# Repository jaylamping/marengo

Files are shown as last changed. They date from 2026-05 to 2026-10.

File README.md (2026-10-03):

<p align="center">
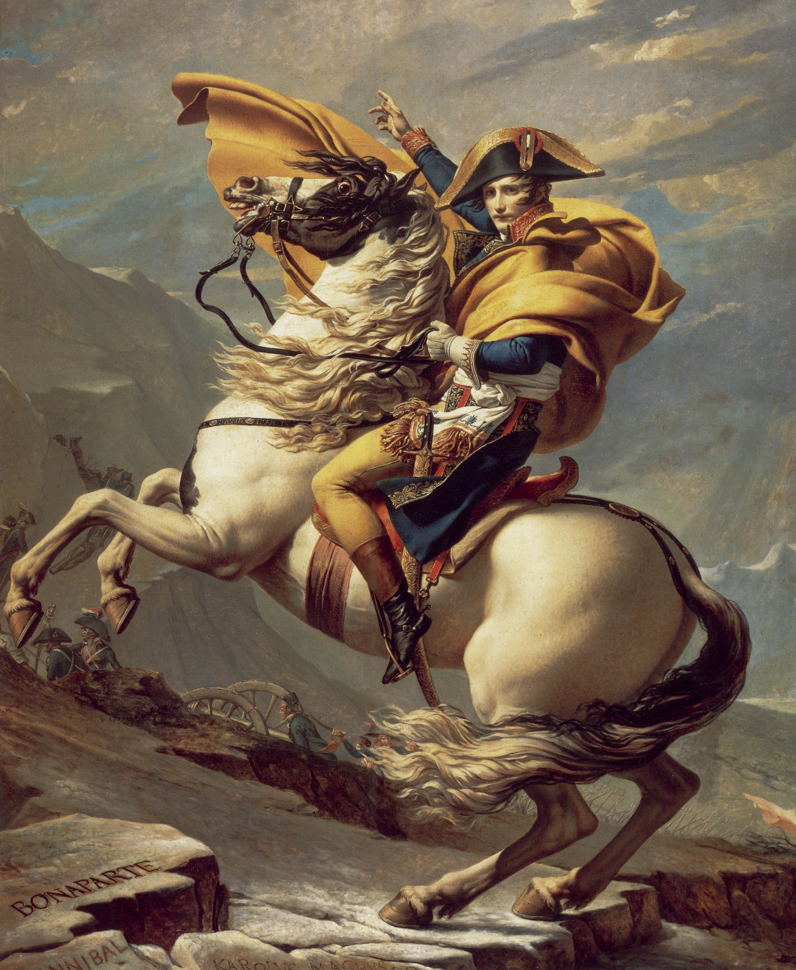
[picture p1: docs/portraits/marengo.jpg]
Jacques-Louis David, Napoleon crossing the Alps on Marengo
  
</p>

# Marengo

Returning to the project: read the [September 2026 repository review](docs/reviews/2026-09-29-repository-review.md) for the current architecture, bench checkpoint, outstanding defects, and ordered repair plan.

One repo for a personal humanoid: CAD, wiring, URDF, and the Rust runtime. SolidWorks and the harness docs define joints, frames, and limits. Control, safety, planning, and the operator UI read that same definition. When the robot changes in CAD, software should change with it.

## Naming

| Name | Role |
|---|---|
| Marengo | The robot (mechanical + electrical design, URDF, runtime) |
| Armée | Rust workspace: shared types, kinematics, crates |
| Chappe | Message bus between processes |
| Berthier | Realtime control |
| Davout | Safety supervision |
| Consul | Web frontend |
| Talleyrand, Fouché | Planner and Jetson vision/LLM: not built; the scaffolds were removed (2026-10-03 crate audit), [ADR 0014](docs/decisions/0014-jetson-perception-semantic-motion.md) holds the design |

Supporting crates: `armee-proto` (protobuf codegen), `armee-kinematics`, `robstride` (CAN driver). Wire schemas live in [`proto/`](proto/). More context: [docs/architecture.md](docs/architecture.md), [docs/roadmap.md](docs/roadmap.md) (full humanoid milestones; the arm is the current bench slice), [ADR 0001](docs/decisions/0001-protobuf-wire-types.md).

## Repository layout

```
marengo/
├── Cargo.toml              # Armée workspace root
├── proto/                  # Protobuf wire types
├── cad/                  # SolidWorks tree (local only); manifests tracked for MCP
│   └── manifests/        # MCP conventions + vendor registry (JSON)
├── hardware/             # Electrical, prints, BOM, hardware docs
│   ├── electrical/       # PDB, harness, CAN docs
│   ├── prints/             # STLs + slicer notes
│   ├── bom/                # Master BOM
│   └── docs/               # Kinematics, assembly, hardware ADRs
├── assets/                 # Exported from hardware, used by software
│   ├── urdf/marengo.urdf   # SW → URDF export
│   └── meshes/             # visual/ + collision/
├── crates/                 # Armée libraries (each has a README)
├── bins/                   # Pi runtimes and dev tools
├── consul/                 # Frontend (Vite + React + TS)
├── models/                 # ONNX policies (Git LFS)
├── config/                 # robot.yaml, motors.yaml, control.yaml, homing.yaml
├── docs/                   # Software architecture + ADRs
└── scripts/                # URDF export, deploy helpers
```

ONNX policies use Git LFS when present. See [.gitattributes](.gitattributes). CAD binaries are local-only — [cad/README.md](cad/README.md).

## Software

### Crates (`crates/`)

| Crate | Codename | README |
|---|---|---|
| `armee-proto` | Armée | [crates/armee-proto/README.md](crates/armee-proto/README.md) |
| `armee-kinematics` | Armée | [crates/armee-kinematics/README.md](crates/armee-kinematics/README.md) |
| `chappe` | Chappe | [crates/chappe/README.md](crates/chappe/README.md) |
| `berthier` | Berthier | [crates/berthier/README.md](crates/berthier/README.md) |
| `davout` | Davout | [crates/davout/README.md](crates/davout/README.md) |
| `robstride` | — | [crates/robstride/README.md](crates/robstride/README.md) |

### Binaries (`bins/`)

| Binary | Host | Purpose |
|---|---|---|
| `marengo-pi` | Raspberry Pi | Control, CAN, Chappe |
| `motor-repl` | Dev | Interactive motor exercise |

### Frontend

[consul/](consul/) is the operator UI and URDF viewer.

## Hardware workflow

1. Design in `cad/` (assemblies: `marengo.SLDASM`, sub-assemblies per limb).
2. Document limits and frames in [hardware/docs/kinematics.md](hardware/docs/kinematics.md).
3. Export URDF and meshes: `./scripts/export-urdf.sh` → `assets/`.
4. Wire and CAN: [hardware/electrical/wiring/](hardware/electrical/wiring/).

Vendor CAD (Robstride, Moteus, extrusions) lives under `cad/vendor/`.

## Build

Windows development and local CAD live at `J:\code\marengo`; macOS uses a host checkout of the same repository. Docker runs the full Linux workspace checks. Start with [Windows and macOS development](docs/windows-macos-development.md) and [onboarding](docs/onboarding.md).

```bash
docker compose build dev
just check
```

Native host setup is optional ([docs/dev-setup.md](docs/dev-setup.md)). Rust conventions for contributors and agents: [docs/rust-patterns.md](docs/rust-patterns.md), [AGENTS.md](AGENTS.md).

Deploy helper: `scripts/deploy-pi.sh`. systemd units: `scripts/systemd/`.

## CI

GitHub Actions runs `scripts/check.sh` in the dev image, plus optional `sim` and `vcan` jobs ([.github/workflows/ci.yml](.github/workflows/ci.yml)).

## License

MIT OR Apache-2.0. See [LICENSE-MIT](LICENSE-MIT) and [LICENSE-APACHE](LICENSE-APACHE).

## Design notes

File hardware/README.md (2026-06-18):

# Hardware

Physical robot design for Marengo: CAD, electrical, prints, and BOM. Mechanics and wiring are defined here first; software reads the exports.

## Layout

| Path | Purpose |
|---|---|
| [`../cad/`](../cad/) | SolidWorks parts, assemblies, vendor STEP, MCP manifests |
| [`electrical/`](electrical/) | PDB (KiCad), harness and CAN documentation |
| [`prints/`](prints/) | STL sources and slicer notes |
| [`bom/`](bom/) | Master BOM and sourcing |
| [`docs/`](docs/) | Kinematics, assembly, hardware ADRs |

## Active design

| Target | Status |
|---|---|
| Humanoid rev-a (G1/R1-class biped, 1524 mm, 23 DOF) | Torso frame 125×150×380 mm committed; pelvis/shell draft — [`docs/kinematics.md`](docs/kinematics.md) |
| Arm (4 DOF, bring-up) | First subsystem wired; [`config/robot.yaml`](../config/robot.yaml) + [`assets/urdf/arm_4dof.urdf`](../assets/urdf/arm_4dof.urdf), subset of humanoid arm kinematics |

Full-body runtime templates (not loaded until remaining joints are commissioned): [`config/robot_humanoid.yaml`](../config/robot_humanoid.yaml), [`config/motors_humanoid.yaml`](../config/motors_humanoid.yaml).

## Revision

When you cut a build, record the mechanical/electrical revision here (e.g. `rev-a`, date, known deltas from prior rev).

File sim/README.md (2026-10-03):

# Simulation fixtures and tests

`check-sim` smokes the minimal fixture plus the production model
[`assets/mjcf/marengo.xml`](../assets/mjcf/marengo.xml) (mirrors
[`assets/urdf/marengo.urdf`](../assets/urdf/marengo.urdf); body inertials are the
URDF CAD values — never hand-tuned). The Rust side (`sim-harness`) checks
URDF↔MJCF parity: joint names, axes, and range containment in the URDF hard
limits.

| File | Purpose |
|---|---|
| `fixtures/minimal.urdf` | Kinematics / URDF validation (`armee-kinematics`) |
| `fixtures/minimal.xml` | MuJoCo headless smoke (`check-sim`) |

## Run locally

```bash
just sim-check
```

Requires `docker/Dockerfile.sim` (MuJoCo Python).

## Environment

- `MARENGO_SIM_MODEL` — path to MJCF (default: `sim/fixtures/minimal.xml`)

[ADR 0003](../docs/decisions/0003-simulation-testing.md).

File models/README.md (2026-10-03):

# Models

ONNX policies and future Jetson-side model weights ([docs/roadmap.md](../docs/roadmap.md) M7; `fouche` was removed, design in [ADR 0014](../docs/decisions/0014-jetson-perception-semantic-motion.md)).

Large binaries use Git LFS (root [.gitattributes](../.gitattributes)).

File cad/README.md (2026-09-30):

# CAD (local only)

SolidWorks models and vendor imports are **not stored in git**. Keep your working tree under `cad/` on your machine (or a separate `marengo-cad` clone at the same path). Joint names, axes, and limits live in [hardware/docs/kinematics.md](../hardware/docs/kinematics.md). After export, runtime reads [assets/urdf/marengo.urdf](../assets/urdf/marengo.urdf).

Root assembly: `assemblies/marengo.SLDASM` (local).

## What stays in this repo

| Path | Purpose |
|---|---|
| `manifests/` | MCP conventions, vendor registry, design packages (text JSON) |
| `vendor/incoming/README.md` | Vendor intake notes |

## Local layout (gitignored)

| Path | Purpose |
|---|---|
| `assemblies/` | Root `marengo.SLDASM` and limb sub-assemblies |
| `parts/` | Marengo-authored `.SLDPRT` by subsystem |
| `vendor/` | Vendor STEP and imported `.SLDPRT` |
| `vendor/incoming/` | Drop downloads here before promoting to `vendor/` |
| `exports/` | Neutral STEP/STL from MCP `solidworks_export` |

## Setup

Software and local CAD sources live together at **`J:\code\marengo`** on Windows.
Open that host checkout for software and SolidWorks
([ADR 0018](../docs/decisions/0018-windows-macos-software-home.md)).

If CAD binaries are restored from backup/LFS archive, put them under that same
tree's `cad/`. macOS uses a host checkout of the same remote repository; ignored SolidWorks files require their own backup and transfer policy.

SolidWorks MCP allowed root is `${workspaceFolder}` (the host workspace) — your
local `cad/` tree must exist there for automation.

## Naming

- Authored part: `marengo_<subsystem>_<part>.SLDPRT` (example: `marengo_shoulder_pitch_mount_bracket_left.SLDPRT`)
- Authored assembly: `marengo_<subsystem>_asm.SLDASM` (example: `marengo_torso_asm.SLDASM`)
- Vendor import: `vendor_<mfg>_<mpn>_vendor.*` (STEP or `.SLDPRT` after import)

Regex targets: [manifests/cad-conventions.json](manifests/cad-conventions.json).

## Custom properties (authored parts)

Required on every Marengo-authored part and every vendor `.SLDPRT` in an assembly (MCP `marengo_design_review` checks the tree).

| Property | Authored example | Vendor import example |
|---|---|---|
| `process` | `cnc`, `print`, `layout` | `purchase` |
| `material` | `6061-T6`, `PETG` | `6063-T5`, `aluminum`, `RS03 actuator (vendor)` |
| `revision` | `A` | `vendor` |
| `owner` | handle or name | same as authored parts |

Batch-apply vendor properties (SolidWorks must be running):

```powershell
cd J:\code\solidworks-mcp
npm run build
npm run set:vendor-props
npm run promote:corner-bracket   # incoming → vendor_2028_corner_bracket_vendor + rewire torso asm
```

## Named reference geometry (URDF handoff)

Required on links and actuated joints before Brawner export:

| Name | Type | Purpose |
|---|---|---|
| `urdf_link_frame` | coordinate system | Link origin for URDF |
| `joint_axis` | axis | Revolute axis (right-hand rule) |
| `cable_exit` | plane or point | Harness routing |
| `mount_face` | plane | Actuator or bracket interface |

See [hardware/docs/kinematics.md](../hardware/docs/kinematics.md) for joint naming.

## Hardware folder

Place fasteners, inserts, and purchased hardware under a top-level feature folder named `Hardware` (see `manifests/cad-conventions.json`). Use real Toolbox or vendor STEP components, not cosmetic-only geometry, so BOM and `marengo_hardware_coverage` can count them.

## BOM alignment

1. Add a row to [hardware/bom/master-bom.csv](../hardware/bom/master-bom.csv) with `part_id` aligned to [manifests/vendor-assets.json](manifests/vendor-assets.json) `id` when possible.
2. Run `marengo_hardware_coverage` before major assembly saves.

## Workflow

1. Model in SolidWorks under `assemblies/marengo.SLDASM` (local).
2. Run `marengo_design_review` before saving assemblies.
3. Export URDF manually (Brawner) → `assets/urdf/marengo.urdf`.
4. Run `scripts/validate-urdf.sh` and update [hardware/docs/kinematics.md](../hardware/docs/kinematics.md) if joints changed.

Open [marengo.code-workspace](../marengo.code-workspace) from `J:\code\marengo` (marengo + solidworks-mcp). Build MCP after worker changes: `npm run build` in `J:\code\solidworks-mcp`. Allowed CAD root is `${workspaceFolder}`.

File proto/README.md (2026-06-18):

# proto

Wire-type definitions for all inter-service messages on [Chappe](../crates/chappe/).

- Edit `.proto` files under `marengo/v1/` (package `marengo.v1`). Never hand-edit generated Rust (`armee-proto`) or TypeScript (`consul/src/gen/`).
- Rust: [prost](https://github.com/tokio-rs/prost) via `crates/armee-proto/build.rs`
- TypeScript: [Buf](https://buf.build) + `@bufbuild/protobuf` from `consul/` (`npm run gen:proto`)
- On the wire: binary protobuf (`encode_to_vec` / `decode`), not JSON

## Prerequisites

- [`protoc`](https://grpc.io/docs/protoc-installation/) for `cargo build -p armee-proto`
- [`buf`](https://buf.build/docs/installation) for `consul` codegen (`npm run gen:proto`)

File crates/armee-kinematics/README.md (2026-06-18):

<p align="center">
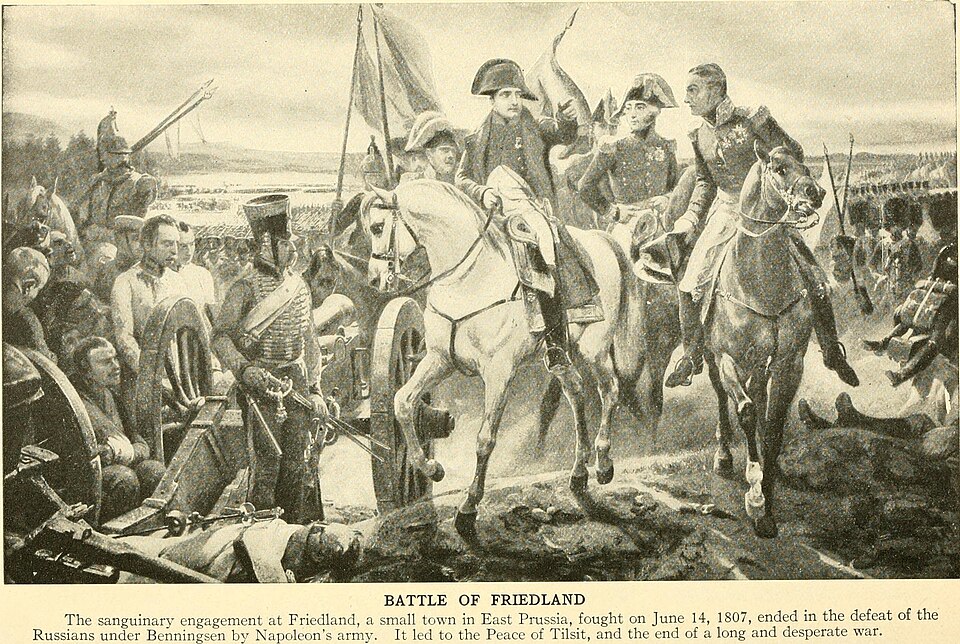
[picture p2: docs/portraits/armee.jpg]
Napoleon at Friedland
  
</p>

# armee-kinematics

Part of Armée, the Rust workspace for Marengo.

Loads joint limits and transforms from [`assets/urdf/marengo.urdf`](../../assets/urdf/marengo.urdf), aligned with [`hardware/docs/kinematics.md`](../../hardware/docs/kinematics.md). Used by planners, controllers, and sim collision checks.

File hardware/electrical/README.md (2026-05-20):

# Electrical

Power distribution, harnessing, and field bus topology for Marengo.

- [`pdb/`](pdb/) — Power Distribution Board (KiCad schematic, layout, BOM)
- [`wiring/`](wiring/) — Harness runs, CAN layout, connector pinouts

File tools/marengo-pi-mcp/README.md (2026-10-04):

# Marengo Pi MCP

MCP server for Marengo bench control on a Raspberry Pi over SSH. Runs on your dev machine; the Pi is only an SSH target.

## Setup

### SSH

```text
# ~/.ssh/config
Host marengo.local
  Hostname marengo.local
  User joey
  IdentityFile ~/.ssh/id_ed25519
```

Verify: `ssh joey@marengo.local 'echo ok'`

If mDNS fails, set `MARENGO_PI_HOST` in the environment before Cursor starts the MCP (or export it in your shell profile). Do not add it to `.cursor/mcp.json` — that env is hashed into Cursor’s MCP approval key and thrashing it auto-disables the server.

### Passwordless sudo (Pi)

`scripts/install-pi.sh` provisions these rules when run as root. For manual repair:

```sudoers
# Marengo MCP — passwordless sudo for bench scripts only (visudo -f /etc/sudoers.d/marengo-joey)
joey ALL=(root) NOPASSWD: /opt/marengo/scripts/can-up.sh *
joey ALL=(root) NOPASSWD: /opt/marengo/scripts/install-pi.sh
joey ALL=(root) NOPASSWD: /home/joey/marengo/scripts/install-pi.sh
```

Not full passwordless sudo. Only these paths.

Verify:

```bash
sudo -n /opt/marengo/scripts/can-up.sh can0 can1
sudo -n /home/joey/marengo/scripts/install-pi.sh   # staging → /opt (use this after deploy)
```

`sudo -n true` fails by design. After editing files under `~/marengo`, run `pi_install_staging` (MCP) or the staging install command above. Do not run `/opt/marengo/scripts/install-pi.sh` alone; it re-copies stale `/opt` content.

### Build MCP server

From repo root:

```bash
just mcp-build
```

Or:

```bash
cd tools/marengo-pi-mcp
npm install
npm run build
```

Restart the marengo-pi MCP server in Cursor after rebuilding.

If a tool still shows old behavior after `npm run build`, the Cursor MCP process is stale. Restart marengo-pi before retrying.

### Cursor `mcp.json`

Repo [`.cursor/mcp.json`](../../.cursor/mcp.json) uses `${workspaceFolder}` so the same file works on **Windows, macOS, and Linux/WSL**.

**WSL / Linux / macOS (software home):** mcp.json uses **`bash` + [`run-mcp.sh`](run-mcp.sh)**. Cursor's spawn PATH often lacks mise `node`, so bare `node` fails with `spawn node ENOENT`. The shell launcher finds mise (or `MARENGO_MCP_NODE`).

**Windows CAD session:** prefer [`run-mcp.cmd`](run-mcp.cmd) / [`run-mcp.ps1`](run-mcp.ps1) — Cursor often lacks Git `sh`/`bash`. Those wrappers exec [`dist/launch.js`](src/launch.ts) once `node` is resolved.

Profile / SSH defaults live in [`src/launch.ts`](src/launch.ts) / `run-mcp.sh` — **not** in `mcp.json` `env` (that thrash auto-disables the project MCP; see [ADR 0016](../../docs/decisions/0016-wsl-software-home.md)).

Open the marengo repo root as the Cursor workspace (WSL software session, or Windows UNC CAD session — ADR 0016).

`MARENGO_LOCAL_ROOT` is optional. The server derives the repo root from its install path. Override only for unusual clone layouts.

After clone or pull that touches MCP sources:

```bash
just mcp-build
```

Then restart the marengo-pi MCP server in Cursor.

**Stay enabled:** `.cursor/hooks.json` runs `session-start-marengo.js` on `sessionStart` (`--write --best-effort`) so disabled/unapproved state is scrubbed when a chat opens. If the server still shows as disabled after a config thrash:

```bash
# Quit Cursor first for a hard write, then:
just mcp-ensure-enabled --write
```

## Tool summary

| Class | Confirm | Examples |
|---|---|---|
| Read-only | No | `pi_logs_tail`, `pi_health`, `pi_homing_status`, `pi_motor_repl_status`, `pi_protocol_inspect`, `pi_gravity_preview`, `pi_imu_probe` |
| Admin | No | `pi_can_up`, `pi_sync_main`, `pi_sync_tree`, `pi_sync_bench_config`, `pi_sync_bench_urdf`, `pi_wait_deploy`, `pi_install_staging`, `pi_git_pull`, `pi_build` |
| Admin | Yes | `pi_restart_marengo_pi`, `pi_clean_tree` |
| Motion | Yes | `pi_motor_disable`, `pi_motor_recover`, `pi_set_zero`, `pi_hold_on`, `pi_hold_off`, `pi_bench_harness`, `pi_marengo_pi_script`, `pi_gravity_calibrate`, `pi_joint_calibrate`, `pi_motion_suite`, `pi_enable_soak` |

Weighted profile (`weighted_single_arm`, `arm_attached`) needs `confirm: true` and `confirm_weighted_motion: true`.

### One CAN owner

`motor-repl status` opens SocketCAN for its probe but bypasses Davout Supervisor
construction, so it sends no startup type-24 active-reporting burst.
`gravity-preview` reads the configured URDF model locally and does not open
CAN. `disable` and `set-zero` are CAN-owning commands; the latter uses Davout's
qualified reference workflow and an independent exit stop. `protocol-inspect`
(ADR 0037) also owns CAN: it stops every drive with Disable only, turns
reporting Off and reads firmware version, MCU id and registers (including the
0x7028 drive CAN timeout) one query at a time; it never enables or writes a
parameter, so `pi_protocol_inspect` needs no confirmation and prints a per-joint
firmware / CanTimeout table. MCP's ownership guard remains conservative: while
`marengo-pi` or any `motor-repl` process runs, `pi_motor_repl_status`,
`pi_protocol_inspect`, `pi_gravity_preview` and `pi_can_up` skip rather than
compete for the bus; stop `marengo-pi` with `pi_restart_marengo_pi` first.

Reference grants live only inside the `marengo-pi` process that acquired them
(ADR 0036). `pi_health`, `pi_homing_status` and `pi_sync_bench_config` (with
`install_to_opt`) therefore:

- while `marengo-pi` runs (`pgrep -x marengo-pi`), show per-joint homing from its own `RobotState`, read from the gateway's `/snapshot/robot/state`;
- otherwise print `no live marengo-pi session: reference grants are process-local (ADR 0036)` and the latest reference journal rows from `scripts/reference-journal-tail.py`, which opens `/opt/marengo/var/calibration/reference-journal.sqlite3` read-only. Journal rows are history and never grant a reference.

`install-pi.sh` runs no homing check; it prints one line pointing at the in-process procedure in [docs/homing.md](../../docs/homing.md).

Motion tools that open CAN take sole ownership of the bus for the session. These are `pi_motor_disable`, `pi_motor_recover`, `pi_set_zero`, `pi_hold_on`, `pi_hold_off`, `pi_marengo_pi_script`, `pi_gravity_calibrate`, `pi_joint_calibrate`, `pi_motion_suite`, `pi_enable_soak` and `pi_bench_harness`. Each session:

1. Stops `marengo-pi.service` with `sudo -n /usr/local/libexec/marengo/pi-restart-marengo-pi.sh stop`, the same helper `pi_restart_marengo_pi` uses. The service runs as `marengo` with `Restart=always`, so a bare `pkill` either fails or lets systemd start a second owner within 5 s.
2. Kills leftover `marengo-pi` processes owned by the deploy user.
3. Refuses to run (exit 1) if any `marengo-pi` or `motor-repl` is still running.
4. Waits for the bus to settle before every marengo-pi launch (`pi_hold_on`, `pi_marengo_pi_script`, `pi_motor_recover`, the harness session) and before restoring the unit. No `marengo-pi`/`motor-repl` may run, and the kernel CAN error counters (`rx_errors`, `rx_over_errors`, `tx_errors`, bus errors, error-passive, bus-off) must hold still for 0.5 s. The log shows `can settle: ok … <counters>`. marengo-pi latches a persistent Transport fault on any CAN error frame, and the mcp251x reports an RX FIFO overrun as one. A motor-repl run ending right before marengo-pi started (two `motor-repl disable`s, then marengo-pi's own type-24 burst) overran it at startup on 2026-10-03. If no window settles within 2 s, the session logs `can settle: FAIL` and refuses to start marengo-pi (exit 1); the unit restore warns and restarts anyway. Bench sessions run one pre-session `motor-repl disable` before the settle. `pi_hold_on` also logs `can errors after marengo-pi: …`, and runs its trailing `motor-repl disable` only once marengo-pi has exited. If marengo-pi still owns CAN, it prints `post-session bin/motor-repl disable skipped: …` and exits 1.
5. Restarts the unit when the session ends if it was active before, the same way `install-pi.sh` restores state. The unit comes back Disabled. The restart runs on every exit path, including errors and SIGHUP/SIGTERM. `pi_bench_harness` restarts it in a final `restore_marengo_pi_service` step.

To keep control off after a session, run `pi_restart_marengo_pi` with `mode: stop`.

### Reference and zero (no Motor Studio)

A current reference is granted only inside the process that acquires it. When that process exits, the grant ends. Acquiring a reference runs SetZero at the joint's current pose, so put each joint at its mechanical reference first.

- `pi_hold_on` and `pi_bench_harness` acquire references inside their own marengo-pi session. They send `home <joints> sign-tested` on stdin and wait until marengo-pi prints `reference <joint> current pos=…` for every joint. Then they send the plain `home`, `enable` and hold lines, so dwell sleeps begin only once the references are held. If a joint prints `reference <joint> failed|skipped: …` or `home failed: …`, or the wait passes 10 s per joint, the session sends `disable` and `quit` and exits 1.
  `pi_hold_on`, `pi_gravity_calibrate` and `pi_joint_calibrate` also await the plain `home` (until `homing verified`) and `enable` (until `enabled (operator=…)`). marengo-pi prints `enabled` only once enable has completed: every target's Enable is written (a just-zeroed drive's is held about 800 ms past its SetZero) and each target has fresh session feedback, after a `waiting for enable to complete` line. On `home failed:`, `enable failed|blocked|refused:` (including an Enable not complete within 2 s) or no answer within 10 s, the session sends `disable` and `quit` instead of any hold line and exits 1, and the tool result names marengo-pi's refusal line.
  `pi_marengo_pi_script` applies the reference wait to any `home <joints> sign-tested` line in its script.
- Both tools require `set_zero: true` **and** `at_mechanical_reference: true`. Without them they refuse before contacting the Pi, so a session never re-zeros at an arbitrary pose. `pi_hold_on` references only `joint` when you give one. If you omit it, it references every joint of the bench profile and holds `right_shoulder_pitch`. `pi_bench_harness` references `joints`, or every joint of the profile, once. It then runs all enable-requiring suites in **one** marengo-pi process: grants survive a clean `disable` but not the process, and re-zeroing per suite would accumulate the return-to-0 tracking error. Before each later suite it checks `$LOG` and stops if an earlier suite failed.
- `pi_set_zero` runs `motor-repl set-zero <joint> --sign-tested`, which prints its own qualified readback (`set-zero <joint> verified pos=…`), then `motor-repl disable`. The grant ends when motor-repl exits, so it doesn't let a later marengo-pi enable.
- `pi_motor_recover` never acquires a reference and never enables. After a fault the arm isn't attested at the reference, so it disables and reads `fault=` from `status` while Disabled.

```json
{
  "confirm": true,
  "joint": "right_shoulder_pitch",
  "set_zero": true,
  "at_mechanical_reference": true,
  "position_rad": 0.1
}
```

`config_dir` defaults to `/opt/marengo/config`. For a 3-DOF harness run, select the harness profile that exports `MARENGO_JOINT_SUBSET`. Don't point `MARENGO_CONFIG_DIR` at a separate bringup tree.

Profiles without a joint subset (`bare_motor`, `weighted_single_arm`, `arm_attached`) reference and gravity-gate exactly the master `config/robot.yaml` joints, `MASTER_JOINTS` in `src/bench-profiles.ts`: right shoulder pitch, shoulder roll, upper-arm yaw, elbow pitch and lower-arm yaw. Subset profiles use robot.yaml-order prefixes of that list. `test/bench-profiles.test.ts` fails when these drift from `config/robot.yaml` or `config/motors.yaml`.

### Gravity-model gate

`pi_hold_on` and `pi_bench_harness` run one shared gate (`src/gravity-gate.ts`) before anything can enable, for every bench profile. It applies the limb-playbook §4a/4b bar: a joint fails when its residual is **≥ 0.20 Nm**. On a failure the tool stops with `FAIL gravity_model_mismatch` and sends no reference, enable or hold line. `pi_hold_on` returns the report. The harness records `[FAIL] gravity_gate` and restores `marengo-pi.service`.

1. Before taking CAN, the gate reads the Pi clock and the gateway's `/snapshot/robot/state`. This read never touches CAN.
2. As sole CAN owner, it runs `motor-repl gravity-preview`. `pi_hold_on` runs it in its own `soleCanOwnerShell` session. The harness runs it as the `gravity_gate` step, after `can_up` and `motor_repl_status`. Non-zero poses use a full `robot.yaml`-order vector. Standalone `pi_gravity_preview` accepts no angles for the all-zero pose or exactly one angle per master joint in order; the harness's weighted previews also pass all five values.
3. It compares results per gated joint. Gated joints are the referenced joints, plus the hold joint for `pi_hold_on`.

| Basis | When | Residual |
|---|---|---|
| `measured` | Snapshot is at most 1 s old, and every gated joint is `drive_active` and `Verified` (marengo-pi is holding the arm) | `\|τ_meas − τ_g(q_published)\|`, where τ_meas is the gateway `effort` |
| `hanging_rest` | All other cases: no gateway, stale snapshot, or drives disabled | `\|τ_g\|` at the profile's `hangingRestRad` (every joint at its mechanical reference, arm down = 0, where physical gravity torque is ~0) |

In practice `hanging_rest` is the basis that applies. Both tools disable drives before their session, and a disabled Robstride carries no phase current: it reports ~0 Nm whatever the arm weighs, so a disabled reading is not a gravity measurement. `at_mechanical_reference: true` attests that the arm is at that rest pose. If none of the gated joints is in the gravity model, or the preview prints nothing (for example CAN is still owned), the gate fails closed with `FAIL gravity_gate_unavailable`.

Do not raise gains to get past this gate. Fix the URDF instead.

### `pi_gravity_calibrate`

Repeatable right-arm gravity-model calibration (`src/tools/gravity-calibrate.ts`; pre-flight, session runner and output directory shared with `pi_joint_calibrate` in `src/tools/calibration-session.ts`). It runs as **one** marengo-pi session, like `pi_hold_on`: `home <profile joints> sign-tested` (awaited), `home`, `enable`, then `hold-at` each static pose of `sweep_joint` with a `settle_sec + measure_sec` dwell, then `hold-at <sweep_joint> 0`, `status`, `disable`, `quit`. The position trace records τ_meas at every pose for the workstation fitter.

- **Sweep.** `sweep_joint` is `right_shoulder_pitch` (default poses `[0, 0.25, 0.48, 0.8, 1.2]` rad, at least 3) or `right_elbow_pitch` (default `[0, 0.25, 0.5, 0.75]`, with the pitch held at `fixed_pitch_rad`, moved there first and returned to 0 last). Poses (2–12, distinct) are sorted. An up pass overshoots to min − `approach_offset_rad` and visits every pose from below; a down pass overshoots to max + δ and visits every pose from above, so the fit can separate friction from gravity.
- **Opt-ins.** `confirm` (+ `confirm_weighted_motion` on weighted profiles), `set_zero` and `at_mechanical_reference` as for `pi_hold_on`, plus `skip_hanging_rest_gravity_check: true`. The gravity gate runs as usual but its hanging-rest `|τ_g|` mismatch ends in `SKIPPED gravity_model_mismatch (hanging rest) for gravity calibration` instead of refusing: the calibration exists to fix that model. Residuals are still reported; `gravity_gate_unavailable` and a measured-basis mismatch still refuse.
- **Limits.** Before any motion a read-only pre-flight (no CAN) reads the Pi `config_dir` `robot.yaml`, `control.yaml`, `motors.yaml` and the URDF `robot.urdf` names. Every target (overshoots included), the fixed pitch and the return pose 0 must lie in `[max(soft, hard) lower, min(soft, hard) upper]` (control.yaml `position_soft_*_rad` ∩ motors.yaml `bench.position_*_rad`), else it refuses naming joint, value and window. The session's sleep + reference budget must be ≤ 300 s.
- **Outputs.** `var/gravity-calibration/<TS>/` on the workstation (gitignored): `plan.json` (steps = the session's `hold-at` lines in order), `position-trace.csv` (Pi trace verbatim), `pi-marengo.urdf` and `config/{robot,control,motors}.yaml` (captured before motion), `bench-session.txt`. With `run_fit` (default) it runs `cargo run --release -q -p marengo-log-cli -- gravity-fit --dir <dir> --out-dir <repo>/docs/commissioning/calibrations --repo-urdf <repo>/assets/urdf/marengo.urdf [--fit mass:<link>|com:<link> …]` using absolute workspace paths; exit 2 means the fitter refused.
- **Never applied.** Review the proposed inertial patch, apply it to `assets/urdf/marengo.urdf`, then run `pi_sync_bench_urdf` as a separate explicit step (ADR 0017).

### `pi_joint_calibrate`

One session of the [right-arm calibration suite](../../docs/commissioning/right-arm-calibration-suite.md) (`src/tools/joint-calibrate.ts`): one joint sweeps while the others hold fixed poses. It runs as **one** marengo-pi session: `home <profile joints> sign-tested` (awaited), `home`, `enable`, a `hold-at` per non-zero `fixed_rad` pose (chain order), the sweep (`method`), then `hold-at <joint> 0` for every profile joint distal first (`return_home_sec` after each moved joint), `status`, `disable`, `quit`. `pi_gravity_calibrate` stays available unchanged.

- **Sweep.** `sweep_joint` is any of the five right-arm joints; `profile` defaults to `arm_attached`. Default poses are 5, evenly spaced across `amplitude_fraction` (0.25, 0.5 or 0.9) of the joint's soft ∩ hard window, centred on 0 (hanging rest, lowest gravity) and shifted to stay `0.05 rad` plus `approach_offset_rad` (static) or the 0.1 rad maximum wave amplitude (wave) inside the window. `poses_rad` (2–12) overrides them.
- **`method: "wave"` (default).** At each pose (ascending) a `hold-at` park at pose − a (`settle_sec`), then marengo-pi's in-loop `wave <joint> <pose−a> <pose+a> <cycles> <half_period>` at each speed; plan steps carry `pose_index`. A static hold rests anywhere inside the ±F_s stiction band; a wave drives through it both ways, and `gravity-fit` takes the up/down mean per q bin.
  - Amplitude `a = (F_s + 0.6 × max|τ_g at the poses|) / kp`, F_s = control.yaml friction `fs` (else `fc`), kp = `impedance.kp`, τ_g from the τ guard's batch; rounded up to 1 mrad, at least 0.025 rad; above 0.1 rad it refuses. `wave_amplitude_rad` overrides.
  - Speeds: 3, evenly spaced from 0.2 rad/s (gravity-fit's centre bin stays above its 0.15 rad/s deadband) to the admissible wave speed for ±a (0.8 × velocity cap, `position_trajectory_velocity_rad_s`, `position_trajectory_accel_rad_s2`); half period `π·a/v` to 0.01 s. `wave_speeds_rad_s` (2–3, each ≥ 0.2) overrides.
  - Cycles per speed: at least 2, enough for 1.5 × 10 samples per direction in gravity-fit's a/2-wide centre bin at `control.loop_hz`. `wave_cycles` overrides.
  - Adjacent poses must be more than 2a apart. `velocity_passes` refuses (static only); `approach_offset_rad` and `measure_sec` are unused.
- **`method: "static"`.** The `pi_gravity_calibrate` up and down hold passes, then the velocity passes: marengo-pi's in-loop `wave` once per `half_periods_s` entry, after a `hold-at` at `min_rad`. Default: a band up to 0.3 rad wide centred in the pose band, 2 cycles, at 25/50/75 % of the admissible peak speed (half periods rounded up to 0.05 s). `half_periods_s: []` runs holds only.
- **Opt-ins.** As `pi_gravity_calibrate`: `confirm`, `confirm_weighted_motion`, `set_zero`, `at_mechanical_reference`, `skip_hanging_rest_gravity_check: true`.
- **Pre-flight guard.** All before any motion, from the Pi's live `config_dir` and URDF:
  - Every hold target, overshoot, fixed pose and wave extreme lies in `[max(soft, hard) lower + 0.05, min(soft, hard) upper − 0.05]`; the return pose 0 lies in the window.
  - Peak wave speed `π·(max − min)/(2·half_period)` ≤ 0.8 × the joint's velocity cap (control.yaml joint > actuator group > motor type). It must also stay within the joint's `position_trajectory_velocity_rad_s` and `position_trajectory_accel_rad_s2`, and its descent above any `clamp_velocity` danger zone threshold (`peak·√(1 − u²)`, `u = (max(above, centre) − centre)/amplitude`) within the zone speed, all of which marengo-pi's wave admission enforces. Planned waves (motion suite, velocity passes, local waves at each pose) are sized to fit.
  - Total sleep + reference budget ≤ 300 s, else it refuses and suggests splitting the session.
  - τ guard: `|τ_g| × factor ≤ 0.8 ×` τ_ff cap on every profile joint, at configurations ≤ 0.05 rad apart along every commanded path. The paths are each fixed joint moving out in chain order (the distal-first return retraces them) and the sweep across all of its targets, poses and 0 (wave method: planned with the 0.1 rad maximum amplitude, a superset of the final waves). The cap is `min(URDF effort, motors.yaml torque_limit_nm, robot.yaml max_joint_torque_nm, motor-type tau_ff_max_nm)`. τ_g comes from one batched remote call, run as sole CAN owner like the gravity gate, that runs `motor-repl gravity-preview` once per distinct configuration with a full `robot.yaml`-order vector. A missing τ_g refuses. The wave method checks limits, speeds and the budget after this batch, once the amplitude is known.
  - τ guard factor (`src/tau-factor.ts`): 1.6 per joint, or `1 + max(3σ_A/A, 0.15)` for a joint listed in [`docs/commissioning/calibrations/applied-gravity.json`](../../docs/commissioning/calibrations/applied-gravity.json) when its accepted record is in the repo, the Pi URDF's gravity-model fingerprint (link masses and COMs, joint origins and axes; not limits) equals the entry's `urdf_gravity_sha256`, the Pi URDF carries the record's fitted COMs, and every other joint sits at the fit's fixed pose. A missing, unreadable or stale index or record keeps 1.6 (fails closed); the output lists each joint's factor and why. `npm run gravity-fingerprint [urdf]` (after `npm run build`) prints the fingerprint for a new entry. Details: [right-arm calibration suite](../../docs/commissioning/right-arm-calibration-suite.md#calibrated-joints-τ-guard-factor).
- **Outputs.** The `pi_gravity_calibrate` directory with `plan.json` version 2 plus `method`. Wave plans add `wave_amplitude_rad` and omit `approach_offset_rad`/`measure_sec`; static plans keep them. Steps carry `kind`: `hold` (`joint`, `target_rad`, `measure`, `pose_index`, `approach`), `fixed` (`joint`, `target_rad`) or `wave` (`joint`, `min_rad`, `max_rad`, `cycles`, `half_period_s`, and `pose_index` for wave-method local waves). `session_complete` is true only when marengo-pi exited 0 and the trace shows every step, in order. A hold or fixed step counts when `target_raw` changes to its target. A wave counts when it reaches its top `cycles` times and returns to its bottom. With `run_fit` the fit runs even on an incomplete session; the fitter uses completed steps only, and follows plan.json `method`.

### `pi_motion_suite`

Thorough single-joint motion test (`src/tools/motion-suite.ts`), scored per move by `scripts/analyze-position-trace.py --score-bench`. It reuses the `pi_joint_calibrate` session runner, so each session is one marengo-pi process: `home <profile joints> sign-tested`, `home`, `enable`, the motions, every profile joint back to 0 distal first, `status`, `disable`, `quit`. The sweep joint is traced every tick (`MARENGO_POSITION_TRACE_FULL_RATE_JOINTS`) so the τ_ff step is scorable.

- **Usable window.** The soft ∩ hard window (`max` of the lower limits, `min` of the upper) inset by 0.05 rad, narrowed to the run of 0.05 rad samples around 0 where model `|τ_g| × factor ≤ 0.8 ×` τ_ff cap on every profile joint (one batched `motor-repl gravity-preview`; factor as for `pi_joint_calibrate`). Refused under 0.2 rad. Gravity extremes are the largest-|τ_g| samples on each side of 0; a side within 0.15 rad of 0 has none. With the calibrated pitch (× 1.15; 1.15 × 2.66 Nm = 3.06 Nm ≤ 4 Nm) the master config's window is the full inset window [−1.038, 2.93] rad; unverified (× 1.6) it stops at 1.2 rad.
- **Speed-controlled moves.** `hold-at` always runs at the configured planner speed, so a move at a chosen speed is a single-cycle `wave a b 1 T` (a→b→a), with peak speed `speed_fraction × v_adm(b − a)`; `v_adm` = min(0.8 × velocity cap, trajectory velocity, √(accel · span/2)).
- **Sessions** (`sessions`, default all, in order):
  - `long_moves`: bands of `span_fractions` (25/50/90 %) of the window, centred on 0; one wave per `speed_fractions` (25/50/90 %).
  - `sweeps_and_reversals`: full-width waves at the same speeds; then per band `hold-at a`, `hold-at b`, and `hold-at a` again after the trapezoid time to half the move (a mid-move reversal).
  - `short_moves`: 0.02/0.05/0.1 rad out (toward 0) and back at each gravity extreme and at 0.
  - `gravity_extremes`: `hold_sec` (≥ 10 s) drift holds at both extremes, with the moves between them.
  - `repeatability`: 0 → end of the 25 % band → 0, `repeat_count` (5) times.
- **Budget.** Each session must fit 300 s with reference acquisition (50 s for five joints) and the return; a longer one splits at block boundaries into `<name>_1`, `<name>_2`, …. Master pitch config with the repo URDF (window [−1.038, 1.2] rad, upper bound τ): `long_moves` 156 s, `sweeps_and_reversals` 132 s, `short_moves` 134 s, `gravity_extremes` 87 s, `repeatability` 95 s.
- **Guards**, all before any motion of any session: every target and wave extreme ≥ 0.05 rad inside the window, wave speed and acceleration within the admission limits, the τ guard along every commanded path of every session, the budget, `confirm` (+ `confirm_weighted_motion`), `set_zero` + `at_mechanical_reference`. The gravity gate before each enable keeps its hanging-rest refusal.
- **Outputs.** Per session `var/motion-suite/<TS>/`: `plan.json` (version 1: session, window, extremes, steps, `budget_sec`, `session_complete`), `position-trace.csv`, `bench-session.txt`, `config/`, `pi-marengo.urdf`, `score.txt`. The result ends with a `session | ts | budget s | verdict` table and `overall: PASS|FAIL`. The suite stops at the first session that is refused, fails or is incomplete; a scorer FAIL does not stop it. `dry_run: true` returns the plan after every guard, without any session.

### `pi_enable_soak`

No-motion enable reliability check (`src/tools/enable-soak.ts`). Run it after firmware, wiring or software changes, before more supervised motion.

- **Cycles.** Each of `cycles` (1–50, default 20) is a **fresh** marengo-pi process, launched after its own CAN settle, so startup type-24 sync, streams inherited from the previous process, the post-SetZero blackout and the staggered Enable are exercised every time. Stdin is exactly `home <profile joints> sign-tested` (awaited), `home` (awaited), `enable <operator>` (awaited, polled every 20 ms and timed), `sleep dwell_sec` (0.5–10, default 2), `status`, `disable`, `quit`. It never sends hold, gravity, torque, impedance or wave lines; `test/enable-soak.test.ts` checks the script and the generated remote command for motion verbs.
- **Opt-ins.** `confirm`, `set_zero` and `at_mechanical_reference`. Every cycle re-zeroes at the current pose, so the arm must hang limp at its mechanical reference throughout. `profile` (default `arm_attached`) picks the referenced joints; subset profiles export their `MARENGO_JOINT_SUBSET`. `stop_on_fault` (default false) stops after the first unclean cycle. Plans estimated over 480 s (20 s + cycles × (6 s + dwell)) are refused.
- **Why neutral.** While operational=Active and control=Disabled, Berthier sends only kp=0, kd=0, velocity=0, torque_ff=0 MIT per active joint (a status solicit at the current pose), and Davout's filter and stop path keep it neutral. Only stdin hold/gravity/impedance/torque/wave lines or a Chappe testing command (`robot/testing/mit_command_batch`, forwarded by the gateway from Consul Testing hold/wave) leave ControlMode::Disabled. So each soak marengo-pi runs under `env -u MARENGO_CHAPPE_SOCKET`: stdin is its only command source, and the gateway shows no RobotState during the soak. Every MCP-started marengo-pi (soak or not) also claims motion ownership through `MARENGO_MOTION_OWNER=stdin` in the remote preamble (`src/env.ts`): a Consul tab can then only disable/stop it, and its refused enable/Testing/Set Zero commands are published as `motion_refused` events on `robot/audit/action` (see docs/safety.md, "Single motion owner").
- **Per cycle.** References acquired (n of joints), the enable outcome line, fault or refusal lines (Transport, DriveState, homing verify, watchdog, non-zero `fault=0x…`, ERROR lines, feeder/settle refusals), enable → `enabled` ms, can0 `rx_over_errors` and `rx_errors` before and after, and the exit status. A cycle is clean when it exited 0, printed `enabled (operator=…)`, acquired every reference and logged no fault line.
 - **Outputs.** One candump covers the whole session, as for the other bench tools. Each UP interface is recorded with an error mask (`can0,#FFFFFFFF`), so kernel CAN error frames (e.g. the mcp251x RX-overflow controller report) land in the same capture with kernel timestamps; `firmware-timing` decodes them into `kernel_error_frames` (timestamp, interface, error class, controller flags) and the soak report prints a short `kernel error frames:` section (diagnostic only, never PASS/FAIL). The bench log and candump are copied to `var/enable-soak/<TS>/` (gitignored) with `soak-summary.txt`, and `cargo run --release -q -p marengo-log-cli -- firmware-timing --json candump.log` writes `firmware-timing.json` when the checkout has the analyzer.
- **Verdict.** PASS only when every requested cycle ran clean, can0 `rx_over_errors` did not increase over the session, and firmware-timing ran and reported `non_neutral_mit.count` 0. A non-neutral frame is FAIL regardless of anything else, and so is a missing, failing or unparseable analyzer result (`wire-level neutral-MIT check unavailable`): the soak never passes without the wire-level proof.

```json
{ "confirm": true, "set_zero": true, "at_mechanical_reference": true, "cycles": 20, "dwell_sec": 2 }
```

### `pi_sync_main`

1. Local `git pull --ff-only` on `main` (fails if dirty)
2. `./scripts/deploy-pi.sh joey@marengo.local`
3. Remote `install-pi.sh` → `/opt/marengo`
4. Writes `/opt/marengo/.deploy-rev`

### `pi_restart_marengo_pi`

Stops leftover `marengo-pi` processes and restarts `marengo-pi.service` so Davout reloads boot config (URDF + YAML). Numerical Set Limits Apply hot-reloads live limits and write-behind URDF without restart ([ADR 0012](../../docs/decisions/0012-config-db-overrides.md) / [ADR 0017](../../docs/decisions/0017-bench-set-limits-urdf-expand.md)); use restart for binary deploy, structural wiring, or after a failed persist left disk stale. Requires `confirm: true`. Optional `mode: "stop"` skips systemd start. Does not touch `marengo-gateway`.

Canonical remote body: [`scripts/pi-restart-marengo-pi.sh`](../../scripts/pi-restart-marengo-pi.sh) (also used by `pi-remote.sh restart-marengo-pi` / `stop-marengo-pi`, and Consul `POST /control/restart-marengo-pi`). MCP embeds the local checkout copy so the tool works before the Pi has the new script installed.

```json
{ "confirm": true }
```

### `pi_sync_tree`

Sync the Pi staging checkout (`MARENGO_PI_STAGING_ROOT`, default `~/marengo`) with `origin/main` without building or installing. Fails if that tree is dirty. `pi_git_pull`, `pi_clean_tree` and `pi_build` work in the same checkout. `/opt/marengo` is the root-owned install tree and isn't a git checkout.

1. `git fetch origin`
2. `git checkout main`
3. `git pull --ff-only origin main`

## Session logs

Motion runs tee to `$MARENGO_ROOT/var/log/bench-latest.log`. Read with `pi_logs_tail` / `pi_logs_last_fault`.

Session registration calls `/opt/marengo/bin/marengo-log-cli` directly. If that binary is unavailable or registration/archive fails, MCP leaves the hot log, trace and candump files in place; it does not prune unarchived evidence.

### Motor recover (no Motor Studio)

```json
{ "confirm": true }
```

Tool: `pi_motor_recover`. Disable drives, brief `status` with `fault=0x…`, prints `RECOVER_OK` or `RECOVER_FAIL`. Optional: `"config_dir": "/opt/marengo/config"`; omission uses the same master directory.

## Skills

- [`.cursor/skills/marengo-pi-mcp/SKILL.md`](../../.cursor/skills/marengo-pi-mcp/SKILL.md) — log-first bench workflow
- [`.cursor/skills/marengo-pi-sync/SKILL.md`](../../.cursor/skills/marengo-pi-sync/SKILL.md) — sync-with-main deploy

Also [docs/pi-commissioning.md](../../docs/pi-commissioning.md).

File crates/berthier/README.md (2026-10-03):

<p align="center">
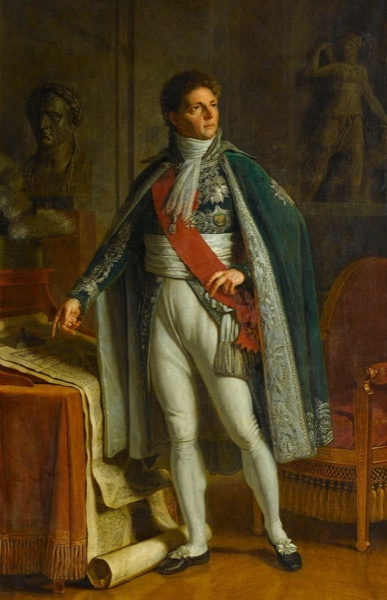
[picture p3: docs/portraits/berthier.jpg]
Louis-Alexandre Berthier
  
</p>

# berthier

Berthier runs the realtime control loop.

Trajectory tracking, mode switching, command output to motor drivers. Consumes joint setpoints (no planner crate exists; see [ADR 0014](../../docs/decisions/0014-jetson-perception-semantic-motion.md)) and limits from [Davout](../davout/).

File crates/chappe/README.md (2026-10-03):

<p align="center">
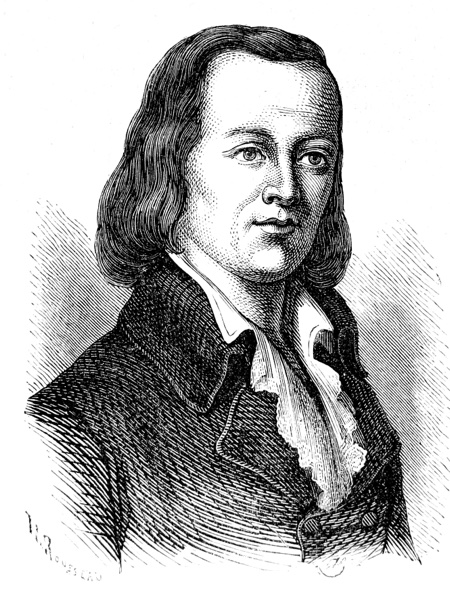
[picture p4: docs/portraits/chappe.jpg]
Claude Chappe
  
</p>

# chappe

Chappe is Marengo's message bus.

It connects runtime components (control, safety, diagnostics) between Pi and tools. Payloads are `Vec<u8>` binary protobuf from [`proto/`](../../proto/), encoded and decoded via [`armee-proto`](../armee-proto/) (`prost::Message::encode_to_vec` / `decode`). No JSON on the wire.

Operator gateway ([ADR 0008](../../docs/decisions/0008-chappe-webtransport-transport.md)): [`bins/marengo-gateway`](../../bins/marengo-gateway/) exposes HTTP CRUD and WebTransport to browsers (Consul). `marengo-pi` forwards publishes over a Unix socket (`MARENGO_CHAPPE_SOCKET`, default `/run/marengo/chappe.sock`).

Planned NATS/MQTT backends use the same bytes-on-the-wire contract.

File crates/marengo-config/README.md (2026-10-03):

# marengo-config

Loads [`config/robot.yaml`](../../config/robot.yaml). Call `resolve_urdf_path` before runtime when you need the production URDF.

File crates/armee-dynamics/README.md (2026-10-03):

# armee-dynamics

Gravity torques and dynamics helpers for Marengo control ([ADR 0005](../../docs/decisions/0005-dynamics-library.md)).

## API

- [`DynamicsModel::gravity_torques`](src/lib.rs) — feedforward for MIT `torque_ff`
- [`UrdfGravityModel`](src/lib.rs) — built from a URDF path + actuated joint list
- [`calibration`](src/calibration.rs) — fit link mass scale / COM offset to bench holding torques
  (`marengo-log-cli gravity-fit`; workflow in [limb playbook](../../docs/commissioning/limb-playbook.md#gravity-calibration-after-hardware-changes))

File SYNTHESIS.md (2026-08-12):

# Ascent-stall recovery — arena synthesis

## Base

**candidate-5** — explicit `AscentRecovery { Idle | Active { stalled_ms } }`; planner advances instead of freezing; existing lead clamp + stuck-lead resync provide bounded authority; fuse sticky across resync.

Parent initially preferred candidate-1 (freeze + lead-follow escalator). Cross-judge preferred candidate-5 for cleaner lifecycle and fewer load-bearing special cases (no resync-suppression footgun). Parent agreed: same authority class (reach `max_lead` P-torque), easier to extend.

## Grafts

| From | Kept | Why |
|---|---|-----|
| candidate-1 | `PlannerEvent::AscentBreakaway`, `ascent_stall_ms` on hold diag + 1 Hz log, motion-release test | Observability + mutation-resistant “progress clears fuse / planner resumes” lock without changing C5’s law |
| candidate-4 | fuse-survives-resync timing assertion (`fault_tick − fuse_armed ≤ 410`) | Locks sticky fuse against silent resync resets; no CSV schema change |

## Rejected

| Candidate / idea | Why |
|---|-----|
| candidate-1 as base | Lead-follow rewrite + resync suppression while frozen is load-bearing; removing the gate fail-opens |
| candidate-2 | Snap-resync at 0.03; test asserts `max_lead < 0.04` — never delivers breakaway torque |
| candidate-3 | Sticky fuse + onset, still freezes at ~0.03 — underpowered for the friction knee |
| candidate-4 as base / remove freeze alone | Same family as C5 but larger surface (CSV column); C5’s named state is the cleaner boundary |
| candidate-4 CSV `ascent_stall_ms` column | Contract churn; diag + 1 Hz log is enough |
| Unify freeze/resync at 0.03 without sticky fuse | Fail-open retry loop (C1 mutation) |
| Re-enable `approach_stuck_mit_pull` | Documented open-loop grind regression |

## Dropouts

None. All five candidates produced artifacts + `RATIONALE.md`.

## Verification

- `cargo test -p berthier`: 155 lib + 2 integration passed
- `cargo clippy -p berthier --all-targets -- -D warnings`: clean
- `cargo fmt --all -- --check`: clean

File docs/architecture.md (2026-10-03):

# Architecture

Current implementation status and known failures are recorded in the [September 2026 architecture and repository review](reviews/2026-09-29-repository-review.md). The working robot is the five-joint right bench arm; planning/perception and some physical homing/simulation capabilities shown below remain future work.

CAD, kinematics, and wiring describe the machine. The Rust workspace (Armée), message bus, control, safety, and planning consume that description. Scope and milestone order: [roadmap.md](roadmap.md).

Wire types are defined once in [`proto/`](../proto/) as Protocol Buffers and generated into Rust ([`armee-proto`](../crates/armee-proto/)) and TypeScript ([`consul/src/gen/`](../consul/)). [ADR 0001](decisions/0001-protobuf-wire-types.md).

## Data flow (high level)

```mermaid
flowchart LR
  HW[cad/ + hardware/docs] --> Assets[assets/]
  Assets --> KIN[armee-kinematics]
  Proto[proto/*.proto] --> AP[armee-proto]
  Proto --> ConsulGen[consul/src/gen]
  AP --> Chappe[Chappe bus]
  ConsulGen --> Consul[Consul UI]
  HW --> Consul
  Pi[marengo-pi] --> Chappe
  Gateway[marengo-gateway] --> Chappe
  Consul[Consul UI] -->|HTTP + WebTransport| Gateway
  Chappe -->|"binary protobuf"| Berthier[Berthier control]
  Berthier --> Davout[Davout safety]
  Davout --> Motors[robstride / moteus]
```

## Control stack boundaries

Motor path is fixed: Berthier → Davout → robstride. Each crate documents its boundary at the top of `src/lib.rs`.

| Crate | Owns | Must not |
|---|---|---|
| [`berthier`](../crates/berthier/) | Joint-space trajectory executor: `tau_g` + impedance → MIT batch | CAN, limits, Cartesian IK, behavior scripts |
| [`davout`](../crates/davout/) | Enable FSM, filter, watchdog, send | Trajectories, URDF dynamics |
| [`robstride`](../crates/robstride/) | MIT encode/decode, CAN I/O | Policy, safety |
| [`armee-dynamics`](../crates/armee-dynamics/) | `gravity_torques(q)` | CAN, commands |
| [`armee-kinematics`](../crates/armee-kinematics/) | URDF limits, joint lists | Control loop |
| [`marengo-config`](../crates/marengo-config/) | YAML types/loaders | Runtime enforcement |

## Crates and binaries

See the root [README](../README.md#software) for the naming map (Napoleonic corps → subsystem).

## Dev tooling

[`dev-setup.md`](dev-setup.md): `protoc`, `buf`, and regeneration workflow.

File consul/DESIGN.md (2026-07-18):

# Consul Design

**Consul** is the personal daily-driver operator cockpit for Marengo.

It exists for one person (you) who will live in it for hours every day while building, debugging, and tuning a 23-DOF humanoid. It must be the sexiest, smoothest, most *functional* robotics operator interface on the planet in 2026.

## The Only Filter

Every pixel, interaction, and feature must survive this question:

> Does this make me faster, more certain, or more in control of the physical machine right now?

If the answer is “no” or “only a little,” it does not exist.

## Current Phase

Consul is **wireframe + live telemetry** when `VITE_CHAPPE_*` is set. KPI cards, charts, inventory rows, and header badges still use placeholders by default; joint tracking, safety/mode badges, and inventory values can reflect real `RobotState` / `SafetyState` from `marengo-gateway` over WebTransport.

The **Simulation** tab is the planned home for Isaac Sim / Isaac Lab: viewport stream, play/pause/scenario controls, runtime metrics, and task logs. Same wireframe rules apply until the D2 Lab bridge shares `proto/` with the stack ([ADR 0003](../docs/decisions/0003-simulation-testing.md)).

## Core Principles

### 1. Information is sacred
- The goal is **understanding**, not data volume.
- Raw logs, metrics, and messages are only valuable when transformed into **actionable, time-synced, context-rich surfaces**.
- No infinite listviews. No firehoses. No “everything everywhere all at once.”
- The 3D view, plots, joint inspector, safety state, and event stream are all locked to the same time cursor. Scrubbing tells a story.

### 2. The 3D visualizer is first-class
- This is not a widget. It is the primary way the physical robot feels *present* on screen.
- Selection, highlighting, measurement, camera choreography, ghosting, contact viz, and exploded views must feel native and delightful.
- Tight bidirectional coupling: click a link in 3D → the rest of the app snaps to that joint/state. Scrub time → the model moves with every other surface.

### 3. Every tunable thing is a knob or dial
- If the robot exposes it in config, YAML, or at runtime (gains, limits, gravity compensation, safety zones, friction models, presets, behaviors…), it must be reachable and changeable from Consul with the same directness as turning a physical potentiometer.
- Changes must be instant to see in the 3D view and live plots.
- Perfect recall, versioning, and one-click restore of any previous “I liked it when it felt like this” state.

### 4. Smoothness and immediacy are non-negotiable
- The UI must feel *obscenely* good. 60 fps interactions, zero perceptible lag on knob drags or 3D camera moves, command palette that appears before you finish thinking the shortcut.
- React 19 compiler, modern web primitives, and obsessive attention to frame times and input latency.

### 5. Modern stack only
- We use the sharpest tools available in 2026 (React 19, WebTransport for messaging when the transport ADR lands, whatever state + data solution actually feels lightest and most powerful).
- We do not inherit 2018–2024 ROS/webviz patterns because “that’s what everyone does.”

## What “Functional + Sexy” Actually Looks Like Here

- You open Consul and in < 3 seconds you know the health and posture of the entire machine.
- You want to change a single joint’s `kd` while watching the 3D arm and the torque error plot — it feels like one continuous thought.
- When something goes wrong at 2 a.m., the thing that matters (the violated limit, the bad gain, the exact pose) is already highlighted or suggested.
- The interface disappears when you are in flow and only appears when you need leverage.

## Nice-to-Haves (for later)

- Teleoperation (high-quality, low-latency, with the same 3D + knob surface)
- Session recording + perfect replay with parameter snapshots
- Multi-robot / fleet views (only after the single-robot experience is god-tier)

## Anti-Patterns (will be rejected on sight)

- Marketing chrome, big logos, “delightful” animations that cost attention
- Enterprise SaaS visual language (Formant-style)
- Generic “dashboard” widgets that look good in screenshots but slow you down in practice
- Anything that makes the 3D view feel secondary
- Any feature whose primary justification is “other people might find this useful”
- GLINUI signature components (Meteor Shower, Typewriter, Pulsating Button) on operator data routes
- Frosted glass / backdrop blur on any surface (retired 2026-07 — the “Launch Day” reskin)
- Decorative motion or idle “alive” effects other than the dust backdrop drift
- Gradients for beauty (legibility aids like the vignette excepted)
- Playful empty states, illustrations, easter eggs

## Visual identity — “Launch Day”

Consul looks like the console a SpaceX engineer has open on launch day: calm, dense, perfectly aligned mono telemetry on near-black, where color is so scarce that a hue change means something. This is instrumentation for expensive hardware — nothing playful survives review.

- **Surfaces:** opaque layered panels (`--surface-0..3`) on a blue-black void, hairline borders (`--line` / `--line-strong`). No blur, no frost.
- **Accent:** amber phosphor (`--accent`, ≈ #FFB000) with armed/caution semantics — active controls, armed machine state, chart-commanded series, focus rings. Never decoration.
- **Status palette:** `--ok` green, `--warning` amber, `--fault` red, `--info` cyan (sparing). Nothing else carries chroma.
- **Type:** IBM Plex Sans for UI text; IBM Plex Mono for every number, log line, and micro-label (10px uppercase, 0.14em tracking). No display fonts.
- **Radius:** 4px. Sharp instruments, not consumer cards.
- **LEDs (`.led*`):** the only always-on glow; live-link pulses at 2.4s (reduced-motion aware).
- **Corner brackets (`.panel-brackets`):** semantic only — surfaces that act on hardware (e-stop, enable, armed tuning panels). Never on passive cards.
- **Dust backdrop:** soft gray particles drift slowly in a near-black void behind the fullscreen canvas. The air moves; the robot (telemetry) stays rock solid. This is the single sanctioned ambient motion — procedural, no stock imagery.

### Surface and motion tiers

| Tier | Surfaces | Skin | Motion |
|---|---|---|---|
| Chrome | sidebar, header, nav, tabs, control bar | opaque panel + hairline | mount ≤200ms; hover feedback |
| Data | tables, charts, log/inventory rows | panel shell; opaque rows | sort/filter ≤150ms; **no row animation** |
| Hero | empty states, sim idle, welcome | panel + void | stagger enter/exit allowed |

Glow is semantic only: armed (amber), fault (red), live-link (LED). Nominal state never glows. `prefers-reduced-motion` freezes the dust drift and LED pulse. Telemetry springs stay unchanged.

---

This document is the living filter. When in doubt, come back here. If a proposed component, layout, or library cannot be defended against these principles, it does not ship.

The bar is extremely high. That is the point.

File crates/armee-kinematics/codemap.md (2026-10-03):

# crates/armee-kinematics/

## Responsibility
URDF kinematic facts for the Marengo arm: joint limits, actuated joint indexing, and velocity-scaled position command envelope (ADR 0009). **No CAN, no control loop, no dynamics torques.** Serves as the geometric source of truth for config validation and runtime limit enforcement.

## Design

### Core types
- `JointLimits` — hard URDF position limits `(lower, upper)` from `<limit>` element; includes methods `contains(pos)` for checking within bounds.
- `JointLimitBounds` — hard limits plus optional `safety_controller` soft bounds from URDF (soft_lower, soft_upper). Methods: `hard_lower()`, `hard_upper()`, `soft_lower()`, `soft_upper()`.
- `JointLimitPolicy` — runtime limit policy built at startup by Davout from URDF + `motors.yaml` + `control.yaml`. Composed of: hard bounds, velocity cap, tau_ff max, LimitMarginConfig, danger zone rules. Used by Davout's filter pipeline and Berthier's position-hold setpoint clamping.
- `LimitMarginConfig` — per-joint margin tuning: `kinetic_margin_rad`, `stop_margin_rad`, `measured_fault_slack_rad`, `linear_margin_rate`.
- `UrdfError` — error enum for file loading, missing joints, parse failures.

### Modules
- `limits` — velocity-scaled position limit envelope (ADR 0009):
  - `limit_margin_rad(dq_cmd, margin)`: kinetic margin = linear_margin_rate * |dq_cmd| + stop_margin.
  - `effective_command_bounds(policy, q, dq_cmd)`: [lo, hi] = [hard_lower + margin, hard_upper - margin]; clamped to soft bounds when present.
  - `clamp_position_in_envelope(policy, q, dq_cmd, position_rad)`: clamp a commanded position into the effective envelope.
  - `clamp_hold_target(policy, q, dq_cmd, requested_rad)`: clamp operator hold-at target; soft bounds first, then envelope at dq_cmd.
  - `measured_position_fault(q, policy)`: true when measured position exceeds hard limits + fault slack.
  - `approach_velocity_cap(policy, q, dq_cmd, v_max)`: scale down cruise v_max when approaching an envelope wall.

### Key functions
- `load_urdf(path)` — parse a URDF file with urdf-rs.
- `joint_limits(robot, name)` — extract hard position limits for a named joint.
- `joint_limit_bounds(robot, name)` — hard limits plus safety_controller soft bounds (URDF soft is a fallback; Davout overwrites it from `control.yaml`). Errors (`UrdfError::InvalidLimits`) on non-finite/inverted hard or non-finite soft limits.
- `joint_entry_count(robot)` — total URDF joints (including fixed/mimic).
- `actuated_joint_names(robot)` — revolute/continuous/prismatic joints in URDF document order.
- `actuated_joint_count(robot)` — count of actuated joints.

### Fixtures module
- `fixtures::arm_4dof_urdf()`, `fixtures::marengo_urdf()`, `fixtures::invalid_urdf()` — checked-in test fixtures under `sim/fixtures/`.
- `fixtures::fixture_path(name)` — resolve fixture path.

## Flow
```
Startup (Supervisor::from_repo):
  → armee-kinematics::load_urdf(path)
  → armee-kinematics::joint_limit_bounds → JointLimitBounds
  → build_limits → JointLimitPolicy per joint
  → stored in Supervisor.limits

Per-tick (Davout filter and Berthier):
  → clamp_position_in_envelope(policy, q, dq_cmd, position_rad)
  → approach_velocity_cap(policy, q, dq_cmd, v_max)
  → clamp_hold_target(policy, q, dq_cmd, requested_rad)
  → measured_position_fault(q, policy) → fault in Davout check_feedback_position
```

## Integration
- **Depends on**: `urdf_rs` (URDF parser). No other workspace crate dependencies — deliberately leaf-level.
- **Depended upon by**: `armee-dynamics` (load_urdf for gravity model), `davout` (limit policy building + runtime clamping), `berthier` (position-hold setpoint clamping).
- **Does not**: compute tau_g, send commands, open files beyond URDF loading, run a periodic loop.
- **URDF is the geometric source of truth**: keep `hardware/docs/kinematics.md` in sync when joints change.

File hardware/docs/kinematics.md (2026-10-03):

# Kinematics

Single source of truth for joint names, axes, limits, link dimensions, and actuator assignment. Software, URDF, and bench config should match this doc.

| Model | URDF | Status |
|---|---|---|
| Right arm (5 DOF, live) | [`assets/urdf/marengo.urdf`](../../assets/urdf/marengo.urdf) | Current master SoT; same arm chain as the target humanoid, not a separate robot |
| Historical slices | [`assets/urdf/archive/seed-*/contributor.urdf`](../../assets/urdf/archive/) | Archive seeds only; never selected as the live runtime SoT |

Full-body target: [`config/robot_humanoid.yaml`](../../config/robot_humanoid.yaml) + [`config/motors_humanoid.yaml`](../../config/motors_humanoid.yaml). Live bench: master [`config/robot.yaml`](../../config/robot.yaml), [`config/motors.yaml`](../../config/motors.yaml), and [`assets/urdf/marengo.urdf`](../../assets/urdf/marengo.urdf) for the wired right 5-DOF arm. Old 3-DOF and 4-DOF contributors are preserved at [`archive/seed-arm_3dof_right/contributor.urdf`](../../assets/urdf/archive/seed-arm_3dof_right/contributor.urdf) and [`archive/seed-arm_4dof_right/contributor.urdf`](../../assets/urdf/archive/seed-arm_4dof_right/contributor.urdf). Milestones: [`docs/roadmap.md`](../../docs/roadmap.md).

---

## Humanoid mechanical reference

Design follows **Unitree G1** upper-body proportions and **Unitree R1** lower-body slimness, scaled to **1524 mm (5 ft)**. No wheels — biped only.

Design status: only the [upper torso 2020 frame](#torso-frame-committed) is committed for rev-a CAD. Pelvis, shell, battery bays, shoulder poke, and leg lengths below are draft and may change during layout. Joint names, axes, and actuator map stay authoritative.

| Parameter | Unitree G1 | Marengo (draft unless noted) |
|---|---|---|
| Standing height | 1320 mm | **1524 mm** |
| Body width | 450 mm | *draft* — shell TBD |
| Chest depth | 200 mm | *draft* — shell TBD |
| Thigh + shank (link length) | 600 mm | **660 mm** |
| Shoulder → hand reach | ~450 mm | **~480 mm** |
| Target mass (with battery) | ~35 kg | **38–42 kg** |
| Total DOF (v1, no hands) | 23 | **23** |

### Torso frame (committed)

Upper body structure is a single **2020 aluminum cage** (`marengo_upper_torso_frame` in CAD). Depth = **+X forward**, width = **±Y**, height = **+Z** from pelvis bottom origin.

| | Depth (X) | Width (Y) | Height (Z) |
|---|---|---|---|
| **Outer (2020 OD)** | **125** | **150** | **380** |
| **Inner clear (between rails)** | **85** | **110** | **~300** above waist bay |

| Feature | mm | Notes |
|---|-----|---|
| **Waist bay** (bottom of frame) | **≥ 40** | Reserved for `waist_yaw` RS03 + adapter; no shelves |
| **Chest zone** (above waist bay) | **~340** outer | Pi, PDB, harness; M18 bay *draft* |
| **Bottom interface** | — | Bottom rail → waist adapter → pelvis ring (*pelvis draft*) |
| **Top interface** | Z = **495** from pelvis bottom | Shoulder RS03 mounts on outer Y faces (*poke draft*) |

Vertical: **380 mm** = waist joint plane → shoulder plane when pelvis height remains **115 mm** (draft).

### Link dimensions (mm)

Floor → crown must sum to **1524 mm**. Values marked *draft* are CAD targets until vendor STEP and layout freeze.

| Segment | Length | Floor → landmark |
|---|---|---|
| Foot (sole → ankle axis) | 80 *draft* | ankle @ 80 |
| Shank (ankle → knee) | 325 *draft* | knee @ 405 |
| Thigh (knee → hip) | 335 *draft* | hip @ 740 |
| Pelvis block | 115 *draft* | waist @ 855 |
| Torso (waist → shoulder) | **380** | shoulder @ **1235** |
| Neck | 65 *draft* | |
| Head (chin → crown) | 224 *draft* | crown @ **1524** |

| Part | Size (mm) | Status | Notes |
|---|---|---|---|
| **Upper torso frame** | **125 × 150 × 380** outer; **85 × 110** inner clear | **committed** | 2020 cage; see [torso frame](#torso-frame-committed) |
| Pelvis ring | ~215 × 260 × 115 outer *draft* | draft | Wider than torso; main pack bay TBD |
| Main battery envelope | ~185 × 165 × 90 *draft* | draft | Pelvis; max Wh TBD |
| M18 HD12 aux bay | ~168 × 98 × 112 *draft* | draft | Upper back cantilever |
| Shoulder outer width | ~230 *draft* | draft | 150 frame + RS03 poke (~40 mm/side); verify STEP |
| Hip span (joint centers) | ~250 *draft* | draft | R1-class; splayed mounts |
| Foot (each) | 250 × 115 × 80 *draft* | draft | Toe-heavy for CoM |
| Head | 175 × 160 × 224 *draft* | draft | Skipped in v1 CAD |
| Upper arm (per side) | 215 *draft* | draft | |
| Forearm (per side) | 195 *draft* | draft | |
| Hand / gripper stub | 90 *draft* | draft | v1 — no dexterous hand |

### Leg kinematic tree (each side)

Pelvis → **hip yaw** → **hip roll** → **hip pitch** → thigh → **knee** → shank → **ankle pitch** → **ankle roll** → foot.

Yaw is the outboard joint at the pelvis (G1/H1-style). Document any CAD reversal in the assembly drawing; joint names and axes here are authoritative.

---

## Actuator assignment (humanoid)

Peak torque ratings from [ADR 0002](decisions/0002-robstride-protocol.md) (confirm in vendor PDF before production).

| Model | Peak τ | Count | Joints |
|---|---|---|---|
| **RS04** | 120 Nm | **4** | `left_hip_pitch`, `right_hip_pitch`, `left_knee`, `right_knee` |
| **RS03** | 60 Nm | **9** | `left/right_hip_roll`, `left/right_hip_yaw`, `waist_yaw`, `left/right_shoulder_roll`, `left/right_shoulder_pitch` |
| **RS02** | 17 Nm | **8** | `left/right_ankle_pitch`, `left/right_ankle_roll`, `left/right_upper_arm_yaw`, `left_elbow`, `right_elbow_pitch` |
| **RS00** | 17 Nm | **2** | `left_wrist`, `right_lower_arm_yaw` |

**Leg rationale:** RS04 on **inner hip pitch** (primary stance/swing load) and **knee** (single-support peaks, G1-class ~90 Nm knee). RS03 on **outer hip** roll/yaw. RS02 on ankles.

**Arm rationale:** RS03 shoulders (same as bring-up arm); RS02 for yaw, elbow; RS00 for wrists (5 DOF per arm, G1-aligned).

---

## Humanoid joint table

Mirror limits left/right unless noted. Effort column = motor peak τ (Nm). Angles in radians unless noted.

### Waist (1 DOF)

| Joint | Actuator | Parent → Child | Axis | Lower | Upper | Effort | Notes |
|---|---|---|---|---|---|---|---|
| `waist_yaw` | RS03 | pelvis → torso | Z | -2.71 | 2.71 | 60 | G1: ±155° |

### Left leg (6 DOF)

| Joint | Actuator | Parent → Child | Axis | Lower | Upper | Effort | Notes |
|---|---|---|---|---|---|---|---|
| `left_hip_yaw` | RS03 | pelvis → left_hip_yaw_link | Z | -2.76 | 2.76 | 60 | G1: Y ±158° |
| `left_hip_roll` | RS03 | yaw → left_hip_roll_link | X | -0.52 | 2.97 | 60 | G1: R −30°..+170° |
| `left_hip_pitch` | RS04 | roll → left_thigh | Y | -2.69 | 2.69 | 120 | **Inner hip**; G1: P ±154° |
| `left_knee` | RS04 | thigh → shank | Y | 0.0 | 2.88 | 120 | G1: 0–165°; no hyperextension |
| `left_ankle_pitch` | RS02 | shank → left_foot | Y | -1.0 | 0.8 | 17 | Tune after foot CAD |
| `left_ankle_roll` | RS02 | pitch → left_foot | X | -0.5 | 0.5 | 17 | `kd` max **5** |

### Right leg (6 DOF)

Same limits as left; roll/pitch signs follow right-hand URDF convention.

| Joint | Actuator | Parent → Child | Axis | Lower | Upper | Effort |
|---|---|---|---|---|---|---|
| `right_hip_yaw` | RS03 | pelvis → right_hip_yaw_link | Z | -2.76 | 2.76 | 60 |
| `right_hip_roll` | RS03 | yaw → right_hip_roll_link | X | -2.97 | 0.52 | 60 |
| `right_hip_pitch` | RS04 | roll → right_thigh | Y | -2.69 | 2.69 | 120 |
| `right_knee` | RS04 | thigh → shank | Y | 0.0 | 2.88 | 120 |
| `right_ankle_pitch` | RS02 | shank → right_foot | Y | -1.0 | 0.8 | 17 |
| `right_ankle_roll` | RS02 | pitch → right_foot | X | -0.5 | 0.5 | 17 |

### Left arm (5 DOF)

| Joint | Actuator | Parent → Child | Axis | Lower | Upper | Effort | Notes |
|---|---|---|---|---|---|---|---|
| `left_shoulder_pitch` | RS03 | torso → left_shoulder_pitch_link | Y | -0.9 | 3.17 | 60 | Soft −50°…+180° (`safety_controller`); **upright hazard** when q > ~0.5 rad |
| `left_shoulder_roll` | RS03 | pitch → left_shoulder_roll_link | X | -1.57 | 1.57 | 60 | Torso-mounted pitch; roll on arm sub-asm |
| `left_upper_arm_yaw` | RS02 | pitch → left_upper_arm | Z | -1.57 | 1.57 | 17 | |
| `left_elbow` | RS02 | upper_arm → left_forearm | Y | 0.0 | 2.5 | 17 | **Upright hazard** — verify G-comp sign |
| `left_wrist` | RS00 | forearm → left_hand | Y | -1.6 | 1.6 | 17 | G1 wrist pitch band ~±92.5° |

### Right arm (5 DOF)

| Joint | Actuator | Parent → Child | Axis | Lower | Upper | Effort |
|---|---|---|---|---|---|---|
| `right_shoulder_pitch` | RS03 | torso → right_shoulder_pitch_link | Y | -0.9 | 3.25 | 60 |
| `right_shoulder_roll` | RS03 | pitch → right_shoulder_roll_link | X | -0.05 | 3.14159 | 60 |
| `right_upper_arm_yaw` | RS02 | pitch → right_upper_arm | Z | -1.57 | 1.57 | 17 |
| `right_elbow_pitch` | RS02 | upper_arm → right_forearm | Y | -0.50 | 1.2 | 17 | **Upright hazard** — verify G-comp sign |
| `right_lower_arm_yaw` | RS00 | forearm → right_hand | Y | -1.6 | 1.6 | 17 |

These are the design limits. The bench URDF carries the wider taught hard envelope ([ADR 0017](../../docs/decisions/0017-bench-set-limits-urdf-expand.md), listed below); Davout intersects it with the measured bounds in `config/motors.yaml`. URDF soft limits are pitch `[-0.872665, 3.20]`, roll `[-0.05, 3.14159]`, yaw `[-1.57, 1.57]`, and elbow `[-0.50, 1.15]` rad per [ADR 0009](../../docs/decisions/0009-dynamic-position-limit-envelope.md).

Right-arm joint origins and link inertials come from CAD as of 2026-10-03 ([derivation](../../docs/commissioning/right-arm-urdf-from-cad-2026-10-03.md)). Printed-part masses are infill estimates until weighed. Re-run the MuJoCo cross-check after changes ([ADR 0005](../../docs/decisions/0005-dynamics-library.md)).

---

## Live 5-DOF right bench arm

This promoted subset of humanoid arm kinematics is the live master model in
[`assets/urdf/marengo.urdf`](../../assets/urdf/marengo.urdf) and is wired per
[`config/robot.yaml`](../../config/robot.yaml).

| Joint | Actuator | Parent → Child | Axis (joint) | Lower (rad) | Upper (rad) | Effort (Nm) | Notes |
|---|---|---|---|---|---|---|---|
| `right_shoulder_pitch` | RS03 | base_link → right_shoulder_pitch_link | Y | -1.43134 | 3.25 | 60 | Soft `[-0.872665, 3.20]`; **upright hazard** when q > ~0.5 rad |
| `right_shoulder_roll` | RS03 | pitch → right_shoulder_roll_link | X | -0.099415 | 3.22308 | 60 | Soft `[-0.05, 3.14159]` |
| `right_upper_arm_yaw` | RS02 | roll → right_upper_arm_link | Z | -1.57 | 1.57 | 17 | Soft equals hard |
| `right_elbow_pitch` | RS02 | upper_arm → right_forearm_link | Y | -1.63191 | 1.60728 | 17 | Soft `[-0.50, 1.15]`; **upright hazard** — verify G-comp sign |
| `right_lower_arm_yaw` | RS00 | forearm → right_hand_link | Y | -3.24409 | 3.24409 | 17 | Soft `[-1.55, 1.55]`; CAN id **5** on `can0`; in CAD the RS00 axis runs along the forearm (Z at q = 0) |

Hard limits are the taught envelope from the Pi URDF on 2026-10-03 ([ADR 0017](../../docs/decisions/0017-bench-set-limits-urdf-expand.md)). Geometry from CAD: the roll axis crosses the pitch axis 73.5 mm outboard of the pitch output face; the elbow axis is 230.4 mm below that point; the RS00 output face is 99.7 mm below the elbow axis. The bench base frame has the arm's front at −X and outboard at +Y ([derivation](../../docs/commissioning/right-arm-urdf-from-cad-2026-10-03.md)).

---

## Upright / elevated poses

Documented incident (arm bring-up): arm elevated, control stopped, arm fell without gravity feedforward. Applies to **`right_shoulder_pitch`** and **`right_elbow_pitch`** on the live bench arm and to the corresponding full-humanoid joints.

Before bring-up tests with elevated shoulder/elbow:

1. Run per-joint `torque_ff` sign test.
2. Use **GravityComp** only until impedance is tuned.
3. Apply `danger_zones` in `config/control.yaml` for `right_shoulder_pitch` + downward velocity.

Leg bring-up: start with **hip pitch** and **knee** RS04 sign tests under load before closing the ankle loop.

---

## Frames

| Frame | Use |
|---|-----|
| `base_link` / pelvis | Biped origin; pelvis `urdf_link_frame` on CAD pelvis (*pelvis draft*) |
| `torso_link` | Upper torso 2020 frame; shoulder **pitch** RS03 inside cage at shoulder plane (rev-a layout) |
| `left_foot` / `right_foot` | Sole contact; Z = floor in standing neutral |
| `left_hand` / `right_hand` | Tool frame placeholder (TCP when gripper defined) |
| `right_forearm_link` | Live right-arm bench tool frame (full humanoid: `left_hand` / `right_hand`) |

Named CAD geometry: see [cad/README.md](../../cad/README.md).

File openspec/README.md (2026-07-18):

# SDD / OpenSpec

Spec-driven development artifacts for Marengo. Default store mode is **openspec** (files only; no memory MCP).

## Layout

```
openspec/
├── config.yaml          # Project context, testing, phase rules
├── specs/               # Main specs (source of truth after archive)
└── changes/
    ├── archive/         # Completed changes (YYYY-MM-DD-{slug}/)
    └── {slug}/          # Active change artifacts + state.yaml
```

## Active change

- **log-api-error-states** — SDD onboarding cycle (Consul log-api error/loading states)

Run `/sdd-explore log-api-error-states` to start the explore phase.

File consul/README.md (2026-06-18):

<p align="center">
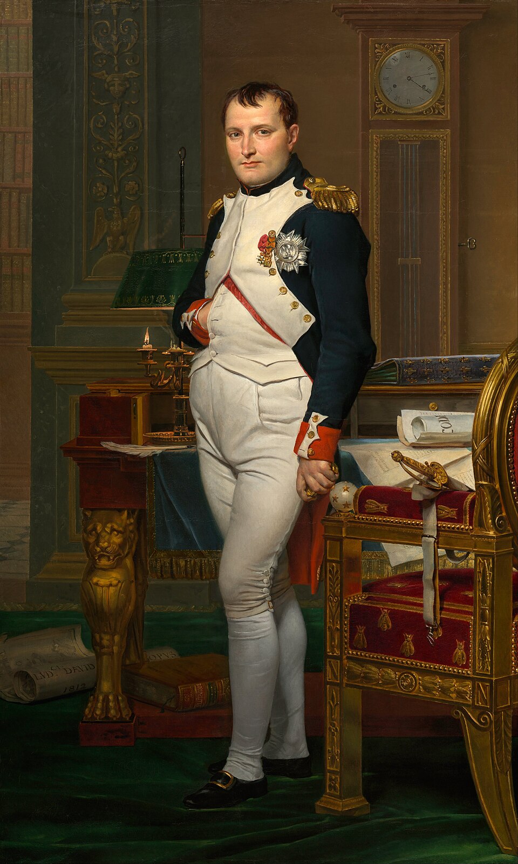
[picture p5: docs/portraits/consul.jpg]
Napoleon in his study
  
</p>

# consul

Consul is the operator frontend for Marengo (Vite + React + TypeScript): robot state, URDF visualization, tuning. Loads `assets/meshes/visual/` and talks to the runtime over Chappe (binary protobuf, same schemas as [`proto/`](../proto/)).

Vite + React 19 dashboard with optional live Chappe telemetry ([ADR 0008](../docs/decisions/0008-chappe-webtransport-transport.md)).

- Robot-hosted (default on Pi): open `https://marengo.local:8444` after `install-pi.sh` / `deploy-pi.sh --install`. Endpoints come from the page origin; WebTransport uses `:8443/chappe`.
- Local dev: copy `.env.example` → `.env.local` with `VITE_CHAPPE_*`, then `npm run dev` on `:5173`.

URDF visualization is still upcoming.

## Development

Requires [`buf`](../docs/dev-setup.md) and Node.js.

```bash
npm install
npm run gen:proto   # ../proto → src/gen/ (gitignored)
npm run build       # tsc --noEmit (CI parity)
```

`gen:proto` runs automatically before `dev` and `build`.

Generated TypeScript uses `@bufbuild/protobuf`. Never edit `src/gen/` by hand.

`DESIGN.md` and `TECH.md` cover principles and current tech choices.

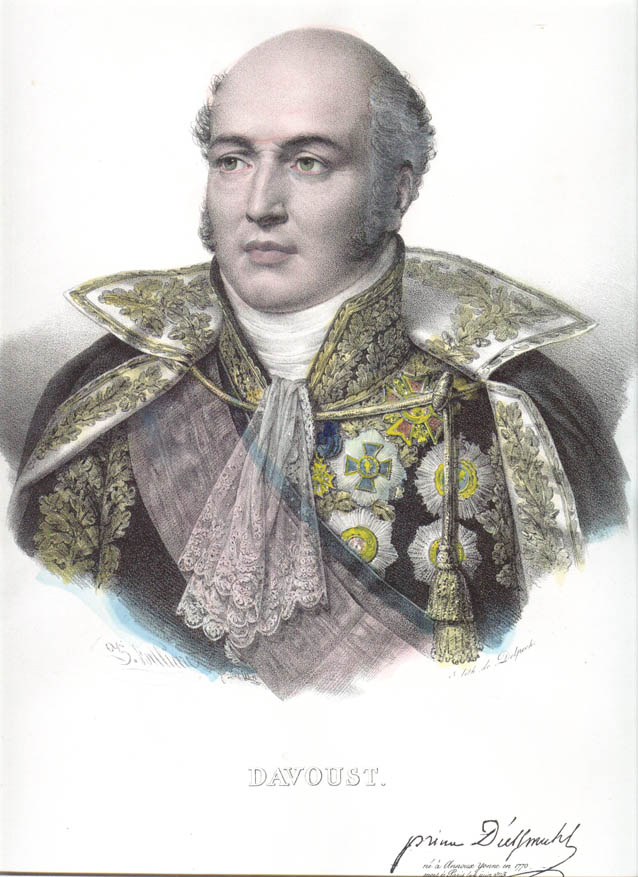
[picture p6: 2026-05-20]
docs/portraits/davout.jpg

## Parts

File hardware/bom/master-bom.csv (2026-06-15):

part_id | description | qty | vendor | mpn | notes
actuator_rs04 | Robstride RS04 joint motor | 4 | Robstride | RS04 | left/right hip_pitch + left/right knee; 120 Nm peak
actuator_rs03 | Robstride RS03 joint motor | 9 | Robstride | RS03 | hip roll/yaw x4 + waist_yaw + shoulder roll/pitch x4; 60 Nm peak
actuator_rs00 | Robstride RS00 joint motor | 2 | Robstride | RS00 | left/right wrist; 17 Nm peak
actuator_rs02 | Robstride RS02 joint motor | 8 | Robstride | RS02 | ankle x4 + arm yaw/elbow x4; 17 Nm peak
stock_vendor_2020_black_extrusion | IXGNIJ 2020 T-slot EU black 500mm (4-pack) | 2 | Amazon | B08Y8KCJW4 | Purchase only (not instanced). Registry: vendor_2020_black_extrusion.
frame_2020_vertical_340 | Torso vertical corner post 340mm | 4 | cut |  |  | Instances frame_2020_vertical_{back|front}_{left|right}_340
frame_2020_bottom_left_100 | Torso bottom left rail 100mm | 1 | cut |  |  | Config L100; depth rail (140 outer / 100 inner)
frame_2020_bottom_right_100 | Torso bottom right rail 100mm | 1 | cut |  |  | Config L100
frame_2020_top_left_100 | Torso top left rail 100mm | 1 | cut |  |  | Config L100
frame_2020_top_right_100 | Torso top right rail 100mm | 1 | cut |  |  | Config L100
frame_2020_bottom_front_110 | Torso bottom front rail 110mm | 1 | cut |  |  | Config L110
frame_2020_bottom_rear_110 | Torso bottom rear rail 110mm | 1 | cut |  |  | Config L110
frame_2020_top_front_110 | Torso top front rail 110mm | 1 | cut |  |  | Config L110
frame_2020_top_rear_110 | Torso top rear rail 110mm | 1 | cut |  |  | Config L110
bracket_2028_corner | 2028 corner bracket 2020 T-slot | 16 | cut |  |  | GrabCAD storm model; 8 cage corners × 2; purchase mankk B0FDKPLF8N
stock_bracket_2028_corner_kit | mankk 2028 corner bracket kit (30 pc) | 1 | Amazon | B0FDKPLF8N | Purchase only (not instanced)
print_shoulder_pitch_mount_bracket_left | PETG shoulder pitch mount bracket (left) | 1 | printed |  |  | marengo_shoulder_pitch_mount_bracket_left
print_shoulder_pitch_mount_bracket_right | PETG shoulder pitch mount bracket (right) | 1 | printed |  |  | marengo_shoulder_pitch_mount_bracket_right
print_waist_yaw_adapter | PETG waist yaw adapter plate | 1 | printed |  |  | marengo_waist_yaw_adapter
sensor_bno085 | Teyleten Robot GY-BNO085 9-DOF IMU | 1 | Teyleten | GY-BNO085 | torso IMU; I2C 0x4b (ADR high); Pi header i2c-1

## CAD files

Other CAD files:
cad/parts/marengo_shoulder_roll_bracket_right.SLDPRT
hardware/cad/exports/marengo_shoulder_roll_mount_bracket_left_revA.STL
hardware/cad/exports/marengo_shoulder_roll_mount_bracket_right_revA.STL

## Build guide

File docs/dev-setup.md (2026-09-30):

# Development setup

## Docker (recommended)

Open the host checkout (`J:\code\marengo` on Windows) and use Docker for full workspace checks. [Windows and macOS development](windows-macos-development.md) describes native frontend work, CAD, and Pi deployment. Dev container setup: [onboarding.md](onboarding.md). Pi bring-up: [pi-commissioning.md](pi-commissioning.md).

```bash
docker compose build dev
just check          # or: docker compose run --rm check
```

Optional:

- Dev Container: Reopen in Container (Cursor / VS Code), [`.devcontainer/`](../.devcontainer/)
- SocketCAN test harness: `just vcan` (Linux, privileged; creates `vcan0`/`vcan1` as test stand-ins for production `can0`/`can1`)
- sim: `just sim-check`

Production runtime uses SocketCAN interfaces named `can0`, `can1`, `can2`, etc. Bring them up on the robot before starting `marengo-pi`, for example:

```bash
sudo ip link set can0 type can bitrate 1000000
sudo ip link set can0 up
```

## Native / host (best-effort)

If you cannot use Docker, install tools matching [mise.toml](../mise.toml):

| Tool | Version |
|---|---|
| Rust | 1.88 (see [rust-toolchain.toml](../rust-toolchain.toml)) |
| Node | 24.16.0 (see [.nvmrc](../.nvmrc), [mise.toml](../mise.toml); matches CI/dev container) |
| protoc | 28.3 |
| buf | 1.47.2 |

### Node on Mac / Windows (avoid lockfile drift)

CI and the dev container use Node 24 (currently 24.16.x). Use mise (or nvm/fnm) so Mac and Windows match CI. Do not rely on an unpinned system Node.

[mise](https://mise.jdx.dev/) (Mac + Windows + Linux):

```bash
# once per machine
mise trust
mise install          # reads mise.toml → Node 24.16.0, Rust, buf, protoc

# in repo root — verify
mise exec -- node -v    # v24.16.0
cd consul && mise exec -- npm ci
```

Alternatives: nvm / fnm read [.nvmrc](../.nvmrc) or [.node-version](../.node-version).

Consul `package-lock.json` rules:

| Task | Command |
|---|---|
| Install deps (day-to-day) | `cd consul && mise exec -- npm ci` or `just consul-ci` |
| After editing `consul/package.json` | `just consul-lock` then commit lockfile |
| Never | `npm install` on Windows/Mac alone to refresh the lockfile — optional deps differ from Linux CI |

`consul/.npmrc` sets `engine-strict=true`; npm refuses Node outside `^24.16.0`.

```bash
# macOS examples (prefer `mise install` for pinned Node 24.16.0 — see above)
brew install rust protobuf bufbuild/buf/buf
git lfs install && git lfs pull

# Pi cross-build from Mac (one-time toolchain + deploy)
./scripts/setup-mac-pi-cross.sh
./scripts/deploy-pi.sh --install joey@marengo.local
# or: just deploy-pi

cargo build --workspace
cd consul && mise exec -- npm ci && npm run gen:proto
./scripts/check.sh
```

Windows Pi cross-builds use the native PowerShell wrapper and Docker caches:

```powershell
Set-Location J:\code\marengo
$env:MARENGO_PI_HOST = 'joey-robot.tail0b414.ts.net'
powershell -NoProfile -File .\scripts\deploy-pi-docker.ps1
```

Use a resolvable Tailscale name or IP because mDNS may not resolve inside Docker. Full native Windows Rust builds are currently blocked by Chappe's Unix IPC types; `just check` supplies the Linux environment. Legacy WSL scripts remain available for explicitly requested use.

## Regenerating wire types

1. Edit `proto/*.proto`.
2. Rust: `cargo build -p armee-proto`.
3. TypeScript: `cd consul && npm run gen:proto`.
4. Update checksum: `shasum -a 256 consul/src/gen/marengo/v1/marengo_pb.ts | awk '{print $1}' > consul/src/gen/.checksum`

Never commit hand-edits to `consul/src/gen/` (gitignored except `.checksum`).

## Dependency updates (manual — no Dependabot)

Monthly (or before releases):

```bash
cargo update
cd consul && npm update   # then: just consul-lock && just consul-ci
just check && just sim-check
```

Review `cargo audit` / `npm audit` output.

## Branch protection

On GitHub, require the **check** workflow to pass before merging to `main`.

## Patterns and safety

- [rust-patterns.md](rust-patterns.md)
- [safety.md](safety.md)
- [troubleshooting.md](troubleshooting.md)

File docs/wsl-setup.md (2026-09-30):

# WSL setup retired

The Marengo owner returned to Windows and macOS host development on 2026-09-29. Open `J:\code\marengo` on Windows; keep the software checkout and local CAD there.

Use [Windows and macOS development](windows-macos-development.md) and [ADR 0018](decisions/0018-windows-macos-software-home.md). Docker provides the Linux runtime checks. Ubuntu is no longer the software home or a required editor session.

The former setup procedure is preserved in Git history and [ADR 0016](decisions/0016-wsl-software-home.md). Legacy setup/deploy scripts are optional for explicitly requested WSL use.

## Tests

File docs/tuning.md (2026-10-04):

# Control tuning (4-DOF arm bring-up)

Operator workflow for OpenArm-style impedance after gravity compensation is validated. See [ADR 0004](decisions/0004-control-modes-and-mit.md).

## Prerequisites

- Per-joint sign test complete ([safety.md](safety.md)).
- `motor-repl gravity-preview` matches expected directions.
- `GravityComp` stable on bench (no free-fall in upright poses).

## Zero pose

OpenArm convention: arms straight down when possible. Record encoder zeros with `SetZero` per motor after mechanical zeroing (`motor-repl set-zero` / `pi_set_zero` — Robstride lifecycle uses host id **0xFD** and set-zero data byte **0x01**, matching Motor Studio).

**Do not confuse:**

| Knob | File | Purpose |
|---|---|---|
| `home_offset_rad` | `config/homing.yaml` | Maps Hall home reference → semantic zero |
| `position_hold_trim_rad` | `config/control.yaml` | Small hold-target fudge only; not homing |

See [homing.md](homing.md).

## Gain sweep

1. Start `config/control.yaml` impedance `kp`/`kd` at documented defaults.
2. **RS03 / RS04 joints** (shoulders, waist, outer hip, **hip pitch**, **knee**): `kd` up to 100; do not copy to RS02/RS00 joints.
3. **RS02 / RS00 joints** (ankles, arm yaw/elbow, wrists): `kd` max **5** per vendor table.
4. Increase `kp` until contact feels crisp without oscillation; back off 20%.
5. **RS03 values tuned before 2026-10-03** (shoulder pitch/roll cruise, accel, slew, `kd`, `fc`, and the `elevated_shoulder_pitch_fall` clamp) were tuned while the drive received `v_des` at 0.4× (wrong ±50 rad/s MIT velocity scale; the drive uses ±20). Re-check them; see [robstride-mit-ranges.md](commissioning/firmware/robstride-mit-ranges.md).

## Friction

Tune `fc`, `fv`, `fo`, `k` under each joint in `config/control.yaml` (Berthier `friction_torque` model).

The ADR 0039 scaled-PD law (per joint `position_law: scaled_pd`, default `legacy`) adds the
optional `friction.fs` / `friction.v_b` Stribeck terms and `position_time_scale_e0_rad`,
`position_integral_band_rad`, `position_integral_leak_s`. Defaults, validation and the Phase 3
entry gate are in [ADR 0039](decisions/0039-position-control-simplification.md); leave every joint
on `legacy` until that gate is met.

## Modes

These are Marengo control modes, not Robstride firmware `run_mode` values. Marengo `Position` still sends MIT operation-control frames with non-zero gains; it does not switch the drive to firmware Position mode (`run_mode=1`).

| Marengo mode | Firmware path | When |
|---|---|---|
| `GravityComp` | MIT `run_mode=0` | First hardware enable, elevated poses |
| `Impedance` | MIT `run_mode=0` | Compliant at current pose (setpoint tracks measured q) |
| `Position` | MIT `run_mode=0` | **Hold-and-return:** latched setpoint via `marengo-pi` `hold-on` / `hold-at` |
| `Position` (legacy) | MIT `run_mode=0` | Only when not holding elevated configurations without G-comp |

### Position hold (`hold-on`)

1. Validate `GravityComp` at arm-down and mid-range first.
2. `enable bench` → wait for `enabled (operator=bench)` → `hold-on` (latches current encoder pose) or `hold-at <rad>`. `marengo-pi` prints `enabled` only once every target's Enable is on the wire and each has fresh feedback (up to ~0.7 s after a fresh `home`, while a just-zeroed drive's Enable is held); a `hold-on` sent earlier waits (`hold-on waiting for enable to complete`) and is refused after 2 s.
3. **`hold-at` ramps** toward the target at each joint's `position_slew_rad_s` (default **0.25 rad/s**). `position_slew_max_lead_rad` caps how far the MIT setpoint may run ahead of measured `q` so P gain stays bounded while the planner catches up.
4. **Planner vs setpoint:** Berthier keeps a rate-limited trajectory in joint space; each tick computes `q_des = clamp(q_traj, q, target, max_lead)`. Gravity FF uses measured `q`; friction and damping FF use **tracking error**, not error to the distant latch target. See [rust-patterns.md](rust-patterns.md) §7 and [ADR 0007](decisions/0007-bench-position-trajectory-control.md#update-2026-06-13-hold-at-plannermit-split).
5. Small push (~±0.1 rad); verify return without oscillation or limit fault.
6. Sweep `impedance.kp` / `kd` in bring-up `control.yaml`; back off 20% from first oscillation.
7. `hold-off` / `disable` before leaving bench.

Firmware Speed mode (`run_mode=2`, `spd_ref`) is a bench diagnostic path only and is disabled unless `control.bench.allow_firmware_speed_mode` is set explicitly.

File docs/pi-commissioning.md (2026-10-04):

# Pi commissioning runbook — dual-shoulder bring-up through single-arm Milestone B.
#
# Hardware confirmed (prototype):
#   left_shoulder_pitch  can1  device_id 12  firmware 0.3.1.42
#   right_shoulder_pitch can0  device_id 1   firmware 0.3.1.42
#
# See also: docs/safety.md, hardware/electrical/wiring/can_topology.md

## Phase 0 — Bench pre-flight

- [ ] CAD joint names deferred; YAML uses `*_shoulder_pitch`
- [x] Firmware IDs: left **12**, right **1**; set-zero after ID change
- [ ] CAN termination verified (`0x3041 can_status` in Robstride tool if bus errors)
- [ ] E-stop ordered: NC mushroom in **motor power** path (TWTADE/Schneider); GPIO 17 sense optional initially

## Phase 1 — Pi OS and CAN HAT

**OS:** Raspberry Pi OS Lite 64-bit (Bookworm). Enable SSH + your public key in Imager.

```bash
sudo apt update && sudo apt full-upgrade -y
sudo apt install -y iproute2 can-utils git i2c-tools
sudo usermod -aG dialout,i2c $USER   # re-login
```

**Waveshare 2-CH CAN HAT (`/boot/firmware/config.txt`):**

```text
dtparam=spi=on
dtoverlay=mcp2515-can0,oscillator=16000000,interrupt=23
dtoverlay=mcp2515-can1,oscillator=16000000,interrupt=25
```

Reboot, then:

```bash
ip link show type can
# Manual (one-off): sudo ./scripts/can-up.sh can0 can1
# Automatic (recommended after install-pi.sh): marengo-can.service enables on boot
sudo systemctl enable --now marengo-can.service
systemctl status marengo-can.service
ip -br link show type can   # expect can0 UP, can1 UP
```

After `install-pi.sh`, `marengo-can` is **enabled and started** — no manual `can-up` needed on each reboot unless the unit failed (check `journalctl -u marengo-can`).

### BNO085 torso IMU (I2C)

Commissioned on the Pi 5 bench: **Teyleten Robot GY-BNO085** on header I2C at **`0x4b`** (ADR/SA0 high; default breakout address is `0x4a`).

**Enable I2C** in `/boot/firmware/config.txt` (requires `sudo`):

```text
dtparam=i2c_arm=on
dtparam=i2c_arm_baudrate=400000
```

Reboot, then verify:

```bash
ls -l /dev/i2c-*
i2cdetect -y 1
# expect 0x4b (Pi 5 uses i2c-1 for header pins; i2c-0 is absent — ignore i2cdetect -y 0 errors)
```

**Wiring (3.3 V logic only):**

| BNO085 | Pi 5 header |
|---|---|
| VCC | 3.3 V (pin 1) |
| GND | GND (pin 6) |
| SDA | pin 3 (GPIO2 / SDA) |
| SCL | pin 5 (GPIO3 / SCL) |

**Rust probe (after deploy):**

```bash
/opt/marengo/bin/imu-probe --bus /dev/i2c-1 --address 0x4b --samples 10
```

**Python smoke test (optional fallback):** Bookworm/Trixie block system `pip`; use a venv with system site-packages so `python3-lgpio` works on Pi 5:

```bash
sudo apt install -y python3-venv python3-lgpio
python3 -m venv --system-site-packages ~/imu-venv
~/imu-venv/bin/pip install adafruit-blinka adafruit-circuitpython-bno08x
# pass address=0x4b to the driver (not default 0x4a)
```

See [hardware/electrical/wiring/harness.md](../hardware/electrical/wiring/harness.md) for harness notes.

**Security (recommended):** SSH key-only, `fail2ban`, `ufw` allow SSH from bench subnet, `unattended-upgrades`.

## Phase 2 — Build Marengo on the Pi

```bash
git clone <repo-url> ~/marengo
cd ~/marengo && git lfs pull
# Install Rust 1.88.0 + protoc (see docs/dev-setup.md native section)
cargo build -p motor-repl -p marengo-pi --features socketcan --release
sudo ./scripts/install-pi.sh
```

Cross-build from laptop: `./scripts/deploy-pi.sh --install joey@marengo.local`. `install-pi.sh` provisions `/opt/marengo`, group-writable config/calibration directories, and narrow passwordless sudo rules for future MCP config sync/install.

**Environment** (`/etc/marengo/env` — template in `scripts/env.example`):

```bash
MARENGO_ROOT=/opt/marengo
MARENGO_CONFIG_DIR=/opt/marengo/config/bringup/shoulder_pitch_dual
RUST_LOG=robstride=info,davout=info,berthier=info,motor_repl=info
```

## Phase 3 — Config profiles

| Milestone | `MARENGO_CONFIG_DIR` | Joints |
|---|---|---|
| **A — dual shoulders** | `config/bringup/shoulder_pitch_dual` | left/right pitch on can0/can1 |
| **A1 — right bench** | `config/bringup/arm_4dof_right` | pitch id 1, roll id 2, yaw id 3, elbow pitch id 4 on can0 |
| **A1 — right 3-DOF regression** | `config/bringup/arm_3dof_right` | roll/pitch/yaw only (no elbow) |
| **A1 — left bench only** | `config/bringup/shoulder_pitch_left_only` | `left_shoulder_pitch` on can1, id 12 (mirrors right tuning) |
| **B — left 4-DOF arm** | `config/bringup/arm_4dof_left` or `config` | all on can0, IDs 11–14 |

**Profile lineage (right arm):** `arm_2dof_right` (historically roll id 1 + pitch id 2) was renamed to `arm_3dof_right` when upper-arm yaw RS02 id 3 landed (`6f70c64`). Pitch/roll directions are unchanged; current right-bench IDs are pitch 1 and roll 2. Active 4-DOF default is `arm_4dof_right` (adds elbow pitch id 4). Limb motion commissioning SoT: [limb-playbook.md](commissioning/limb-playbook.md).

Single-shoulder bench profiles use conservative position hold tuning while feedback velocity guards are active. The current right-only profile uses impedance **kp=8 / kd=1.25**, trapezoid **v=2.0 / a=4.8**, slew **0.15 rad/s**, max lead **0.10**, and trim **0.0** once firmware zero is set at arm-down. Operator shoulder-pitch limits are **[-0.872665, 3.141593] rad** (arm down = 0, -50° to +180°) from URDF `safety_controller`; hard bench/URDF limits are **[-0.9, 3.17] rad**. Berthier/Davout apply a velocity-scaled command envelope (ADR 0009) so fast moves shrink the commandable band before hard limits — full-range sweeps may reach soft limits only after decel, not in one gravity-assisted leg.

### Homing (interim — manual reference)

Until Hall sensors are installed on shoulder roll (see [hardware/docs/homing-sensors.md](../hardware/docs/homing-sensors.md)):

1. Place the arm at mechanical reference (arm down for pitch).
2. Start one long-running `marengo-pi` process.
3. In that process, run `home <joints> sign-tested`; wait for each `reference <joint> current pos=` result, then run `home` and wait for Ready.
4. Run `enable` only after homing succeeds, in the same process.

Do not use `pi_hold_on` with `set_zero: true` unless intentionally recalibrating at mechanical zero.

Full homing contract: [homing.md](homing.md).

Trim `motors.yaml` joint list to only wired actuators while building the arm incrementally.

## Phase 4 — CAN validation (no enable)

```bash
cd /opt/marengo
export MARENGO_CONFIG_DIR=config/bringup/shoulder_pitch_dual

./target/release/motor-repl status

# Single bus debug:
MARENGO_CAN_INTERFACE=can0 ./target/release/motor-repl --can-interface can0 status
```

`status` opens SocketCAN but bypasses Davout Supervisor construction and type-24
active-reporting startup writes. `gravity-preview` reads the configured URDF
model locally and does not open CAN.

**Pass:** `status` reports the configured joint count and loop rate, and confirms
SocketCAN opened. It does not send a probe or active-reporting frame.

Raw bus (motor power on):

```bash
candump -ta can0 &
cansend can0 0300FF0C#0000000000000000   # enable probe id 12
cansend can0 0400FF0C#0000000000000000   # disable
```

## Phase 5 — Safe motor test ([safety.md](safety.md))

Each `motor-repl` command is a **separate process**, and a current reference lives only inside the process that acquired it ([ADR 0036](decisions/0036-physical-robstride-reference.md)). `motor-repl set-zero` grants end when that command exits. Do not use a separate Set Zero process as readiness for a later owner: acquire the reference and enable inside **one** `marengo-pi`. Without a live `marengo-pi`, MCP `pi_health` / `pi_homing_status` say `no live marengo-pi session` and list the latest reference journal rows (history only).

1. E-stop reachable; shoulder supported
2. Sign test per joint (small torque_ff; fix `direction` in YAML if inverted)
3. `gravity-preview` with no angles (zero pose) or a complete angle vector in `robot.yaml` joint order
4. `marengo-pi` with stdin, each joint at its mechanical reference: `home <joints> sign-tested` (wait for `reference <joint> current pos=` per joint), `home` (Ready), `enable bench`, `gravity-on` — **not** `motor-repl gravity-on` alone. Full procedure: [homing.md](homing.md#pi-bench-procedure).

```bash
MARENGO_CONFIG_DIR=config/bringup/shoulder_pitch_dual ./target/release/marengo-pi
# stdin: home <joints> sign-tested / home / enable bench / gravity-on / status / disable / quit
```

### Phase 5b — Limb commissioning

After Pi bring-up and bare-motor sanity, run the limb motion SoT: [limb-playbook.md](commissioning/limb-playbook.md) (Sign → G-comp → … → Limb sign-off).

## Phase 7 — Milestone B (left arm on can0)

```bash
export MARENGO_CONFIG_DIR=config/bringup/arm_4dof_left
motor-repl --can-interface can0 status
```

Commission joints in order: shoulder_roll (11) → shoulder_pitch (12) → upper_arm_yaw (13) → elbow (14).

Remove unmounted joints from `motors.yaml` + `robot.yaml` until each actuator is wired.

## Device ID scheme (commissioned)

| Block | IDs |
|---|-----|
| Right arm | 1–10 |
| Left arm | 11–20 |
| Right leg | 21–30 |
| Left leg | 31–40 |
| Waist + aux | 41+ |

Left arm chain: roll **11**, pitch **12**, yaw **13**, elbow **14**. Right arm: **1–4**.

## Troubleshooting

| Symptom | Fix |
|---|-----|
| `can1` missing | Check `config.txt` typos (`spi=on`, `interrupt=24` not `24n`); `dmesg \| grep mcp2515` |
| `Device or resource busy` on can0 | Already UP — use `ip link show type can` |
| Motor silent | Power, termination, wrong `device_id`, run `candump` |
| Config not found | Set `MARENGO_ROOT` + `MARENGO_CONFIG_DIR` or clone full repo |
| `i2cdetect -y 0` fails | Harmless on Pi 5 — use bus **1** for header I2C |
| No device at `0x4a` | This board uses **`0x4b`** when ADR/SA0 is high |
| `Permission denied` on `/dev/i2c-1` | Add user to `i2c` group (`sudo usermod -aG i2c $USER`), re-login; or re-run `install-pi.sh` |
| `config.txt` edit denied | Use `sudo nano /boot/firmware/config.txt` or `sudo tee` |
| Python `externally-managed-environment` | Use venv (`python3 -m venv`), not `sudo pip3` |
| `ModuleNotFoundError: lgpio` | `python3 -m venv --system-site-packages` + `apt install python3-lgpio` |
| IMU probe timeout / no quaternions | BNO085 uses **SHTP**, not MPU6050-style register reads; confirm `i2cdetect -y 1` shows `0x4b` and wiring is 3.3 V |
| `product id response` timeout | Chip wedged — **stop all `marengo-pi`** (only one I2C client), **power-cycle BNO085** (3.3 V off 10 s), retry `imu-probe` before starting `marengo-pi` |
| `Remote I/O error (121)` at `0x4a` | Wrong address — this bench uses **`0x4b`** (ADR high) |

## Consul (robot-hosted UI)

1. Build/install includes `marengo-gateway` and Consul static assets (`deploy-pi.sh` builds `consul/dist` → `www/`; `install-pi.sh` installs to `/opt/marengo/www`).
2. After `install-pi.sh`, **`marengo-gateway`** and **`marengo-can`** are enabled on boot. Gateway listens on **`[::]:8080`** (HTTP API), **`[::]:8444`** (HTTPS Consul UI), **`[::]:8443`** (WebTransport/QUIC).
3. On the bench LAN, open **`https://marengo.local:8444`** and accept the self-signed certificate once.
4. Run `marengo-pi` manually for live telemetry (`MARENGO_CHAPPE_SOCKET=/run/marengo/chappe.sock` in `/etc/marengo/env`). **`marengo-pi.service` stays disabled** by default — no automatic motor control after reboot. A manual run started from SSH and driven by typed stdin commands must claim motion with `marengo-pi --motion-owner stdin` (or `MARENGO_MOTION_OWNER=stdin`); the default owner is Consul (Chappe), and stdin then only accepts `disable`/`quit`/`status`. MCP sessions claim stdin automatically. See [safety.md](safety.md#single-motion-owner-stdin-vs-chappe).

**Boot state after power loss:** CAN up, gateway/UI up, `marengo-pi` stopped, motors not enabled.

**Local dev (optional):** copy `consul/.env.example` → `consul/.env.local`, then `cd consul && npm run dev` on the dev Mac.

WebTransport uses **QUIC (UDP)**. `ssh -L` forwards TCP only and will not carry `:8443`; use LAN hostnames instead.

Local demo without hardware:

```bash
cd consul && npm run build
cargo run -p marengo-gateway -- --demo \
  --https-listen 127.0.0.1:8444 --web-root consul/dist
```

Then open `https://127.0.0.1:8444`.

## Agent-assisted bench

Cursor agents can drive the Pi over SSH via [`tools/marengo-pi-mcp/`](../tools/marengo-pi-mcp/README.md) (MCP server on your dev Mac).

- **Read-only / logs:** no confirmation — agent should call `pi_logs_*`, `pi_health`, `pi_motor_repl_status` freely.
- **Deploy:** `pi_sync_main` (pull `main`, cross-build, `install-pi.sh`) — pre-authorized.
- **Motion:** `confirm: true`; weighted profile also needs `confirm_weighted_motion: true` after two chat approvals.
- **Session logs:** harness and `pi_marengo_pi_script` tee to `$MARENGO_ROOT/var/log/bench-latest.log`.
- **Limb commissioning SoT:** [limb-playbook.md](commissioning/limb-playbook.md)

```bash
# Manual bench run with session log (same paths MCP uses)
export MARENGO_ROOT=/opt/marengo
mkdir -p "$MARENGO_ROOT/var/log"
./tools/marengo-pi-mcp/harness/log-tee.sh -- /opt/marengo/bin/motor-repl status
```

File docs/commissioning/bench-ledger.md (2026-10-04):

# Bench ledger

One row per bench tool call (one per session for multi-session suites), appended by the `bench-run` skill. Use it to compare runs across commits and to answer "did this fail before commit X?".

Columns:

- **UTC**: run date and time.
- **Session**: the artifact timestamp (`<TS>`).
- **Tool / session**: e.g. `pi_motion_suite/short_moves`.
- **Profile**: bench profile and payload state.
- **Joint(s)**: swept or referenced joints.
- **Rev**: deployed `.deploy-rev`, with `*` when it differs from local HEAD.
- **Cfg**: 8-character config fingerprint (see `bench-run`), or `-`.
- **Question**: what the run was meant to answer.
- **Verdict**: PASS / FAIL / REFUSED / ABORTED.
- **Key numbers**: the few numbers that answer the question.
- **Δrx_over**: change in can0 `rx_over_errors`.
- **Artifacts**: local directory or Pi path.
- **Follow-up**: diagnosis, issue or next run.

| UTC | Session | Tool / session | Profile | Joint(s) | Rev | Cfg | Question | Verdict | Key numbers | Δrx_over | Artifacts | Follow-up |
|---|---|---|---|---|---|---|---|---|---|---|---|---|
| 2026-10-04 20:24 | 20261004T202431Z | pi_motion_suite/long_moves_1 | arm_attached | right_shoulder_pitch | `3ed5c004` | `40b70dfb` | Does scaled-PD J·a + Stribeck (48b76b64) pass the full-range suite? | FAIL | 12/13; slow wave ±0.992 @0.14 rad/s track 0.043 (>0.03); fast moves +0–9 %, stops ≤ 5 mrad, τ step ≤ 0.032 | 0 | var/motion-suite/20261004T202431Z | Stall at slow-wave turnarounds → c5890e3c |
| 2026-10-04 20:26 | 20261004T202646Z | pi_motion_suite/long_moves_2 | arm_attached | right_shoulder_pitch | `3ed5c004` | `40b70dfb` | Same, 90 % span to +2.53 rad | FAIL | 5/6; slow wave −1.04→+2.53 @0.12 track 0.047, 4.5 s stall at peak; no faults, 0 clamps | 0 | var/motion-suite/20261004T202646Z | Tool crashed after scoring (d918c1c7); suite stopped |
| 2026-10-04 21:17 | 20261004T211711Z | pi_motion_suite/long_moves_1 | arm_attached | right_shoulder_pitch | `8703dcca` | `12529488` | Does the friction error assist (c5890e3c, λ 20) fix slow-wave turnarounds? | PASS | 13/13; slow waves within 0.03 | 0 | var/motion-suite/20261004T211711Z | — |
| 2026-10-04 21:19 | 20261004T211926Z | pi_motion_suite/long_moves_2 | arm_attached | right_shoulder_pitch | `8703dcca` | `12529488` | Same, 90 % span to +2.53 rad | FAIL | 6/6 moves pass; 1 total-torque clamp (one-tick dq spike 0.741 rad/s) | 0 | var/motion-suite/20261004T211926Z | Slow-speed audit |
| 2026-10-04 21:22 | 20261004T212243Z | pi_motion_suite/sweeps_and_reversals | arm_attached | right_shoulder_pitch | `8703dcca` | `12529488` | Full-width sweeps and reversals | FAIL | 14/14 moves pass; 1 clamp (dq spike 0.89 rad/s at q +1.80, near the 5 Nm cap) | 0 | var/motion-suite/20261004T212243Z | Slow-speed audit |
| 2026-10-04 21:26 | 20261004T212654Z | pi_motion_suite/short_moves | arm_attached | right_shoulder_pitch | `8703dcca` | `12529488` | Small steps at extremes and 0 | FAIL | 20/22; stops 12.7, 14.2 mrad on descents to 0 | 0 | var/motion-suite/20261004T212654Z | Assist adds stop overshoot |
| 2026-10-04 21:28 | 20261004T212824Z | pi_motion_suite/gravity_extremes | arm_attached | right_shoulder_pitch | `8703dcca` | `12529488` | Holds at −1.038/+1.55, moves between | FAIL | 2/4; stops 10.5, 10.9 mrad (0→−1.038 was 6.3 without the assist) | 0 | var/motion-suite/20261004T212824Z | Assist adds stop overshoot |
| 2026-10-04 21:29 | 20261004T212907Z | pi_motion_suite/repeatability | arm_attached | right_shoulder_pitch | `8703dcca` | `12529488` | Same move ×5 | FAIL | 5/10; returns to 0 stop 10.7–11.1 mrad; MCP server died after this session | 0 | var/motion-suite/20261004T212907Z | Owner: slow motion "fights itself" |

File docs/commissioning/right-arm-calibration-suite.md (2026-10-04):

# Right-arm calibration suite

Status: in build (2026-10-04). Profile `arm_attached`, all five joints referenced
in every session (ADR 0036). Trust nothing from CAD or earlier tuning: each phase
measures gravity and friction on the current hardware, fits, applies, and is
validated before the next phase may run.

## Why

2026-10-04, pitch 0.8 elbow sweep: elbow measured τ ≈ 1.5 × URDF τ_g and
static friction ≈ ±0.14 Nm (config `fc` 0.05). On a downward step the
under-compensated forearm fell at 2.46 rad/s (planned 0.8) and tripped the feedback
velocity fault. The earlier pitch fit (session 20261004T045804Z) was refused:
forearm and upper-arm mass were not separable from one sweep.

## Order and rules

Shoulder first, then down the chain, then compound. Low-gravity poses before
loaded ones. One joint moves per session; the others hold fixed poses.

| Phase | Sweep joint | Fixed poses | Measures |
|---|---|---|---|
| 0 | none | rest | 5-cycle enable soak (wire health) |
| 1 | shoulder_pitch | all others 0 | whole-arm mass × COM about pitch; pitch friction |
| 2 | shoulder_roll | all others 0 | whole-arm mass × COM about roll; roll friction |
| 3a | upper_arm_yaw | all 0 (axis ≈ vertical) | yaw friction only |
| 3b | upper_arm_yaw | pitch 0.5, elbow 0.5 | forearm COM offset about yaw |
| 4a | elbow_pitch | all 0 | forearm + hand mass × COM |
| 4b | elbow_pitch | pitch 0.5 | same, loaded (fit check) |
| 5a | lower_arm_yaw | all 0 | wrist-yaw friction only |
| 5b | lower_arm_yaw | elbow 0.5 | hand COM offset |
| 6 | validation | grid of fixed poses | residual gate, no refit |
| 7 | compound | waypoint sequences | tracking, coupling, repeatability |

Each sweep session (`pi_joint_calibrate`, `method: "wave"` by default):

1. **Local waves** at each pose: park at pose − a, then a raised-cosine `wave`
   [pose − a, pose + a] at 2–3 peak speeds. A static hold rests anywhere in the
   ±F_s stiction band (2026-10-04 pitch: every hold fits `2.35 sin q − 0.09 cos q
   ± 0.37 Nm`), so it cannot place gravity better than F_s; a wave drives through
   stiction both ways. Sizing, from the Pi's config and the model:
   - amplitude a = (F_s + 0.6 × max|τ_g| at the poses) / kp (control.yaml
     friction `fs`, else `fc`; impedance `kp`; 0.6 = the unverified τ guard
     factor − 1, kept for calibrated joints too), at least 0.025 rad, refused
     above 0.1 rad (`wave_amplitude_rad` overrides);
   - peak speeds from 0.2 rad/s (gravity-fit's centre bin stays above its 0.15 rad/s
     moving deadband) to what marengo-pi admits within 80 % of the velocity cap
     (`wave_speeds_rad_s` overrides);
   - cycles per speed so the centre bin collects 1.5 × 10 samples per direction
     (`wave_cycles` overrides); poses more than 2a apart; default poses keep 0.1 rad
     plus the 0.05 rad inset inside the window.
   Amplitude grows by phase run: 25 %, 50 %, then 90 % of the soft window.
2. **`method: "static"`** keeps the earlier session: holds approached from below
   *and* from above (½Δ = Coulomb friction, mean = gravity), then
   constant-velocity passes (`velocity_passes`) in the gravity-free middle.
3. **Pre-flight guard**: refuse any pose whose model τ_g × the joint's uncertainty
   factor exceeds 80 % of the joint's τ_ff cap (wave method: over ±0.1 rad around
   every pose). The factor is 1.6 unless the joint is calibrated (below).

After each phase: fit (gravity-fit, all sessions so far fused), review, apply
the URDF patch (`pi_sync_bench_urdf`, ADR 0017) and friction patch to
`control.yaml` (Pi first; Pi is the source of truth), then rerun that phase's
session as a no-refit check before the next phase.

### Calibrated joints (τ guard factor)

[`calibrations/applied-gravity.json`](calibrations/applied-gravity.json) lists each
joint whose fit is applied: its record and `urdf_gravity_sha256`, the gravity-model
fingerprint of the URDF it was applied to (link masses and COMs, joint
origins and axes; limits excluded, so Set Limits does not invalidate it). The
τ guard of `pi_joint_calibrate` and `pi_motion_suite` then uses factor
1 + max(3σ_A/A, 0.15) for that joint (pitch, 2026-10-04: A 2.661 ± 0.054 Nm → 1.15)
when all hold:

- the Pi URDF has that fingerprint (else the entry is stale);
- the Pi URDF carries the record's fitted link masses and COMs;
- every other joint sits at the fit's fixed pose (0 unless the record says
  otherwise), the only configurations the fit measured.

Anything else, a missing or unreadable index or record included, keeps 1.6;
the tool output lists each joint's factor and why. After applying a fit, add or
update the joint's entry with the fingerprint from `npm run gravity-fingerprint`
in `tools/marengo-pi-mcp` (after `npm run build`). A URDF gravity change makes
every entry stale: refit, or re-pin only after a no-refit check passes.

## Wave fit (`gravity-fit`, wave method)

- **Bins**: each wave in a/2-wide bins at pose and pose ± a/2, split by direction
  (≥ 10 moving samples each way). Per direction the mean of τ − I·q̈ (I from the
  URDF about the swept axis, q̈ the measured second difference); gravity = the
  up/down mean, friction = half the difference at the mean |q̇|.
- **Lumped fit**: with the other joints fixed, the swept joint's gravity is exactly
  `A·sin q + B·cos q` (`armee_dynamics::lumped`). One sweep identifies only A and
  B, not which link is wrong. With ≥ 2 speeds the URDF inertia error ΔI (rotor
  inertia is not in the URDF) is fitted with them; with one speed only the
  centre bins (q̈ ≈ 0) are used.
- **URDF patch**: the smallest COM shift of the carried right-arm links that
  reproduces every fitted A, B, masses unchanged; refused above 0.05 m. The record
  lists how much it moves every other joint's gravity.
- **Friction patch**: fc + fv·|q̇| over the pose/speed bins; `fs` only when the
  Stribeck term (control.yaml `v_b`) is significant, fv only when significant (else
  fc is the Coulomb mean and fv 0, never a slope extrapolated from a narrow speed
  span); independent of the gravity verdict.

## Gates

- Wave method, derived from the data: σ_cross = pooled spread of per-session pose
  means; gate = max(3·σ_cross, torque readout step). Accepted only with ≥ 2 sessions
  sharing a pose, ≥ 3 replicated poses, gate ≤ 0.10 Nm (the data must be repeatable
  enough to check the suite's residual), every replicated pose residual ≤ gate, and
  σ_A, σ_B ≤ gate. A single-bin pose (one wave step of one session, e.g. a wave-edge
  bin) stays in the fit and is reported, but never gates.
- Friction: σ_cross must be repeatable (3·σ_cross ≤ 0.10 Nm), but the residual gate
  and fv/fs significance use the bin noise, max(RMS sampling error of the bins,
  σ_cross): gate = 3·noise, floored at the readout step, capped at 0.10 Nm. A wave
  repeats the same torque swings at the same q every session, so σ_cross understates
  how well a smooth friction model can match bins at other poses.
- Static method: residual |τ_meas − (τ_g + friction sign)| ≤ 0.10 Nm per joint per
  pose; identifiability min singular value ≥ 0.05 Nm, condition ≤ 100.
- No fault, fuse, watchdog or CAN error; no `rx_over` growth; candump + trace
  reviewed after every motion session.
- Phase 6: every grid pose passes the residual gate with the fitted model.
- Phase 7 needs the operator's forbidden-pose list (collisions with torso,
  stand, cables) before any compound move is commanded.

## Tooling

- `pi_joint_calibrate` (MCP): one session = one sweep joint, fixed poses,
  local waves (or static holds + velocity passes), pre-flight guard, ≤ 300 s.
- `marengo-log-cli gravity-fit`: any sweep joint, fused sessions, partial
  sessions (completed steps only); `--method auto|wave|static` (auto follows
  plan.json `method`; `wave` also bins older sessions' velocity-pass waves).
  Proposes the URDF patch and the `control.yaml` friction patch. Nothing is
  applied automatically.

2026-10-04 re-fit of the pitch sessions 084416Z, 084615Z, 102328Z with
`--method wave` (their only waves span ±0.15 rad around 0): B 0.008 ± 0.005 Nm,
A 2.86 ± 0.14 Nm (CAD 2.83 / 0.034), fitted ΔI ≈ 0; refused on identifiability
(σ_A above the 0.023 Nm gate). Friction fc 0.277 Nm, fv 0.199 Nm·s/rad proposed.
Without I·q̈ the same bins give A ≈ 2.2–2.4; with it they agree with CAD within
σ_A, so these narrow waves can neither confirm nor rule out the 17–24 % deficit
the static holds suggested. A wave session across the window decides it.

Phase 1 applied (2026-10-04, sessions 113836Z + 113951Z, waves at five poses across
±0.53 rad, three speeds): A 2.661 ± 0.054, B 0.038 ± 0.016 Nm (CAD 2.832 / 0.034);
max residual 0.021 Nm over the replicated poses against a 0.097 Nm gate. The single-bin
wave-edge poses at q ≈ ±0.026 (+0.135 / −0.118 Nm) are reported, not gated. The URDF patch
moves the carried links' COMs (masses unchanged) to reproduce A, B. Friction: measured
|q̇| spans only 0.16–0.22 rad/s (the 0.076 rad/s velocity quantum), so fv is not
identifiable (0.33 ± 0.74) and no Stribeck term fits; fc 0.353 Nm is the Coulomb mean, with
residual 0.080 Nm against bin noise 0.047 Nm (gate 0.10). Record:
`calibrations/2026-10-04-gravity-20261004T113836Z-20261004T113951Z.md`.

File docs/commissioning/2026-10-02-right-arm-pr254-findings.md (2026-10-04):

# Right arm, 2026-10-02: PR #254 findings (history)

[PR #254](https://github.com/jaylamping/marengo/pull/254)
(`codex/right-arm-commissioning`, 13 commits `dfbf098f`..`fca53e9d`, based on
`ba0fff72`) ran the first enabled tests on the five-joint right arm through a
finite bench owner parallel to the then-unsupported physical reference. It was
closed without merging: [ADR 0036](../decisions/0036-physical-robstride-reference.md)
now owns physical reference, the bench owner enabled 35-57 ms after SetZero
(inside main's 800 ms `POST_SET_ZERO_QUIET`), and the motion ran remotely under a
development-session authorization that main policy does not adopt
(`docs/safety.md`: operators at the robot). This note keeps the measured facts.
Raw receipts and candumps stay on the PR branch under
`docs/commissioning/evidence/2026-10-02-right-arm-*`; none are copied to main.

## Drive facts

- **Firmware is mixed** (disabled protocol inspection, ~20:14 UTC, source
  `e5599c60`): ids 1-2 (RS03) 0.3.1.42, ids 3-4 (RS02) 0.2.3.34, id 5 (RS00)
  0.0.3.32. RunMode read MIT (0), ZeroSta 0, AddOffset 0 and CanTimeout 0 on all
  five. `config/motors.yaml` now records these versions.
- **CanTimeout was written.** The disabled bench-home qualification (21:02:55
  UTC, source `cd033808`, commit `8d8976e9`) wrote CanTimeout (0x7028) = 600
  counts (~30 ms) to all five drives and read 600 back; every later lower-yaw
  run read 600 again. Nothing records the value being cleared or the drives
  being power-cycled, so treat the drive timeout as unknown until 0x7028 is read
  back (`docs/safety.md`, WP-I D2).
- **No blackout after a Disabled SetZero.** In six lower-yaw captures (30
  SetZeros, host id `0xD4`), SetZero went to Disabled drives, which were
  Enabled 35-56 ms later and replied every 5 ms (max gap 5.1 ms) from 450 to
  720 ms after it. Main's blackouts all followed SetZero to an Enabled drive.
  Unverified; see the open item in
  [robstride-firmware-behavior.md](firmware/robstride-firmware-behavior.md).

## Neutral enable

Source `af28b864`: one Enable per drive, 500 ms enabled window of all-zero MIT
commands, 15 accepted stop writes. Lower yaw drifted 9.6 mrad (~0.55°); the
other joints stayed within 0.8 mrad.

## First lower-yaw motion

Commits `b3c243df`..`f2beb0e6`, recorded in `fca53e9d`. Each run commanded lower
yaw 0 → +20 mrad over 400 ms, back over 400 ms, then held zero for the rest of a
1 s enabled window; the other four joints received neutral MIT commands and
torque feed-forward was zero. Each completed run logged 195 five-drive samples
and delivered all 15 stop writes. RMS error compares feedback with the target
at each tick, without lag compensation.

| Source / attempt | kp / kd | Peak (mrad) | Final (mrad) | RMS error (mrad) | Max speed (rad/s) |
|---|---|---:|---:|---:|---:|
| `0f2bb72` / J6R1sx | 10 / 0.4 | 1.5 | 0.4 | 9.65 | 0.077 |
| `0a99e61` / CLyLXZ | 30 / 1 | 10.7 | 0.4 | 5.46 | 0.154 |
| `f2beb0e` / isl5YO | 30 / 0.4 | 19.9 | 6.5 | 5.19 | 0.153 |
| `f2beb0e` / R4DIL3 | 30 / 1 | 15.3 | 6.1 | 4.31 | 0.153 |
| `f2beb0e` / fngbiM | 30 / 2 | 12.7 | 5.0 | 4.89 | 0.177 |

Among the three `f2beb0e` trials, 30/1 had the lowest RMS error and 30/2 the
smallest return error; 30/0.4 nearly reached the 20 mrad peak. 10/0.4 barely
moved, consistent with friction (not modelled). These are single trials, not a
gain recommendation; `config/control.yaml` was not changed.

Three `0a99e61` attempts aborted on the vendor raw velocity field: it read
0.25-0.30 rad/s while the position-derived speed over the same sample interval
was 0.077 rad/s. Raw-velocity guards are noisy at small motions.

## Not established

Return accuracy, repeatability, friction, the other four joints' responses,
gravity compensation, CanTimeout volatility and physical stop distance.

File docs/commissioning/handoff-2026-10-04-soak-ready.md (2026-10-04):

# Handoff 2026-10-04: deployed and CI-green, enable soak is next

Supersedes `handoff-2026-10-04-liveness-hardening.md`; that doc's history (soak table, RX-overrun causes A/B, open decisions, environment) still applies. Read this first.

## State

- **Local `main` = `57f91bb7`, NOT pushed.** `origin/main` = `93b494c3`. Push only after a soak PASS.
- **PR [#255](https://github.com/jaylamping/marengo/pull/255)** (`ci/liveness-hardening`) is at `57f91bb7`; all CI jobs pass (`check`, `vcan`, `sim`, `build-image`). It exists only to run CI; close or merge it once `main` is pushed.
- **Pi `.deploy-rev` = `57f91bb7`** (includes RX-overrun fix A `f49fd9be`). Gateway healthy; `marengo-pi` not running.
- **URDF** right-arm geometry from CAD landed earlier (`903c5a26`); the 2026-10-03 URDF handoff is done.
- User-owned, leave alone: `?? WATCHDOG.yml`, ` M .cursor/mcp.json`. Before `pi_sync_main`: `git stash push -m "local mcp.json host strip" -- .cursor/mcp.json`, pop after.

## Landed this session

|Commit|Change|
|---|---|
|`0431fcf0`|motor-repl `stop_independence` SIGTERM test sends the signal via `nix` (dev-dep) instead of the `kill` binary missing from the CI image. Fixed the PR #255 `check` failure.|
|`84da1838`|Bench session candump records kernel error frames: `candump -t z can0,#FFFFFFFF can1,#FFFFFFFF` (error mask only, keeps receive-all; no `-e`).|
|`54b81a4c`|marengo-candump parses the trailing `ERRORFRAME` marker (those lines were silently skipped).|
|`9e511f98`|`firmware-timing` JSON lists `kernel_error_frames`; error frames no longer perturb gap/load stats.|
|`7664b4e7`|`pi_enable_soak` report prints a `kernel error frames:` section. PASS rules unchanged.|

Merged as `57f91bb7`. MCP rebuilt (`just mcp-build`); the MCP server must be restarted (new omp session does this) to use the new candump.

## Next steps, in order

1. **Soak.** Get the operator to confirm the arm hangs limp at mechanical zero, supported, hands-off. Then `pi_enable_soak {confirm: true, set_zero: true, at_mechanical_reference: true, profile: "arm_attached", cycles: 20}`.
   - PASS = 20/20 clean, can0 `rx_over_errors` unchanged, `non_neutral_mit == 0`.
   - Then grep `bench-session.log` for `grant revoked` and `timestamp unusable` (expect 0), and run `pi_candump_summary`.
   - Cause B (receive blackout after Disabling a Run-mode drive) hit ~3 of 40 recent cycles, so a failure is likely. The `kernel error frames:` section now gives the overflow timestamps and controller flags; correlate them with the host Disable in the candump. Never relax the Transport latch (ADR needed).
2. **Push `main`** after PASS; close/merge PR #255.
3. **Cause B diagnostics** if it recurs (from the previous handoff): user's CANH–CANL resistance (expect ~60 Ω, power off) and can0 ground/shield tie — asked, not yet answered; scope CANH/CANL + MCP2515 INT across a finishing stop; IRQ tracing on CPU0.
4. **Gravity calibration** (`pi_gravity_calibrate`, operator present) and **bench re-check of RS03-tuned values** (velocity scale ±20 rad/s), as listed in the previous handoff.

## Notes

- MCP tests: one run in the main checkout showed 8 transient failures right after a heavy cargo build; three reruns were 210/210. Likely timing-sensitive bash-driven tests under load.
- Agent tooling: a user-level omp extension `~/.omp/agent/extensions/usage-bars.ts` now shows provider usage on the status row (`/usage-style` to change look). Not part of this repo.

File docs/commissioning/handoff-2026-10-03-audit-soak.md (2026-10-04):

# Handoff 2026-10-03: crate audit merged, enable soak PASS, pushed

> Superseded by [handoff-2026-10-04-liveness-hardening.md](handoff-2026-10-04-liveness-hardening.md).

## State

- `main` is pushed to `origin/main`. It contains:
  - all of the 2026-10-03 crate audit: Phase B WP-A through WP-T and prune batches B1–B16;
  - the schema-tolerant reference journal fix (`c6428152`);
  - the two enable-liveness fixes below (`ad1eb887`, `aa773418`), and the ADR 0036 note (`7dbc4870`).
- The workspace is 15 crates and 6 bins (`marengo-homing` was folded into Davout).
- Gate on `aa773418`: fmt and both clippy runs (host and `aarch64` marengo-pi) are clean, and
  `cargo test --workspace` passes. Both fixes were checked red on their baseline and green after.
- The Pi runs `.deploy-rev` = `aa773418…`, deployed with `pi_sync_main` (cross). The gateway is ready and the
  taught limits were preserved.
- `stash@{0}` ("local mcp.json host strip") was popped after the push. `?? WATCHDOG.yml` belongs to the user;
  leave it alone.

## Enable soak (`pi_enable_soak`, profile `arm_attached`, 20 cycles)

|Rev|Dir (`var/enable-soak/`)|Clean|can0 rx_over Δ|non_neutral_mit|Peak frames/10 ms|
|---|---|---:|---:|---:|---:|
|`84e80653`|`20261003T221010Z`|14/20|0|0|67|
|`7dbc4870` (`ad1eb887`)|`20261003T225034Z`|19/20|0|0|65|
|`aa773418`|`20261003T230806Z`|**20/20 PASS**|0|0|63|

Earlier reference points: 42 frames/10 ms in the `edbaebaf` soak and 66 in the `3b4e87e6` soak. No overruns
in any of these three runs, so the stop-burst pacing suspicion from `3b4e87e6` stays unconfirmed.

### Failure 1: the host read gap (fixed in `ad1eb887`)

Symptom: `enable blocked: … full-master Robot Ready` right after `homing verified`, in 6/20 cycles.

- Receive times are host read times.
- stdin/Chappe Enable runs the gravity preflight (64–96 ms on the Pi, 3125 samples) without reading CAN.
- Target resolution then judged grant liveness (`comm_watchdog_ms` = 100 ms) on reads from before the
  preflight. A drive whose post-SetZero blackout covered the last read lost its grant with its reports still
  queued.

The fix:

- `resolve_enable_targets` drains before it builds the facets.
- Non-Active drains judge liveness after reading the queue.
- Active drains are unchanged.
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

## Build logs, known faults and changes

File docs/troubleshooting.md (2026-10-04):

# Troubleshooting

## Container / `just check`

| Symptom | Fix |
|---|-----|
| `protoc: not found` | Use the dev container or `docker compose run --rm check` — do not rely on host protoc. |
| `buf: not found` | Run checks inside the container; for native dev, `cd consul && npm ci`. |
| Permission denied on `target/` | Named volumes owned by root — rebuild dev image and re-run; entrypoint chowns `target/` and `consul/node_modules`. Or `docker compose run --rm --user root dev chown -R marengo:marengo /workspace/target /workspace/consul/node_modules`. |
| `EACCES` on `consul/node_modules` during `just check` | Same as above — ensure `docker/Dockerfile.dev` entrypoint is active (rebuild: `docker compose build dev`). |
| Slow builds on macOS | Ensure the repo is not on a slow bind mount; use named volumes for `target/` (see `compose.yaml`). |

## Git LFS

| Symptom | Fix |
|---|-----|
| Tiny pointer files instead of ONNX | `git lfs install && git lfs pull` |
| SolidWorks files missing after clone | Expected — CAD is not in this repo. Restore locally per [cad/README.md](cad/README.md). |

## SocketCAN

| Symptom | Fix |
|---|-----|
| `Cannot find device can0` | Bring up the production interface: `sudo ip link set can0 type can bitrate 1000000 && sudo ip link set can0 up`. Repeat for `can1`, `can2`, etc. |
| `CAN send failed: No buffer space available` / ENOBUFS (`qlen=10`) | Kernel TX queue too short for mcp251x + multi-motor MIT. `scripts/can-up.sh` sets `txqueuelen` to **1000** (`MARENGO_CAN_TXQUEUELEN` to override). Re-run `marengo-can` / `pi_can_up`, then restart `marengo-pi` (bring-up downs the iface). Verify: `ip -details link show can0` shows `qlen 1000`. |
| Waveshare 2-CH CAN HAT registers but CAN traffic goes `ERROR-WARNING` / `ERROR-PASSIVE` | Verify `/boot/firmware/config.txt` matches the Waveshare 2-CH CAN HAT wiki: `dtparam=spi=on`, `dtoverlay=mcp2515-can1,oscillator=16000000,interrupt=25`, `dtoverlay=mcp2515-can0,oscillator=16000000,interrupt=23`, and `dtoverlay=spi-bcm2835-overlay`. A wrong oscillator value can register `can0`/`can1` while producing bad bus timing. After reboot, `ip -details link show type can` should report `clock 8000000`. |
 | `persistent safety fault 1 (Transport) … received CAN error frame`; `ip -s -s -d link show can0` shows the `overrun` count rising | mcp251x receive overflow: the MCP2515 keeps only two received frames. On the Pi 5 bench its IRQ thread (`irq/*-spi0.0`) is already `SCHED_FIFO` 50 and SPI already runs at the chip's 10 MHz maximum, so neither is a lever. Each transmit runs on a nice-0 per-CPU kworker holding the driver lock the IRQ thread needs; the 2026-10-03 overruns followed ~0.7 ms receive stalls inside host transmit bursts that ended as the queued transmit completed. Davout now spaces Enable and type-24 writes ([safety.md](safety.md)). Untested manual experiment: keep CFS load off CPU0, where every CAN IRQ and that kworker run (`CPUAffinity=1-3` drop-ins for `marengo-pi`/`marengo-gateway`), then compare `rx_over_errors` across sessions. Bench session candumps record kernel error frames (`can0,#FFFFFFFF`) with kernel timestamps: check the soak report's `kernel error frames:` section or `firmware-timing.json` `kernel_error_frames` for the overflow controller flags. The latch stays persistent; restart `marengo-pi` once the bus has settled. |
| Configured motor never appears | Check `config/motors.yaml` `can_interface` + `device_id`; runtime does not auto-register or prune devices. A silent configured motor is a safety fault. |
| Need raw CAN/router logs | Run with `RUST_LOG=robstride=trace,davout=debug,berthier=debug,marengo_pi=info` (or `motor_repl=info`) to log SocketCAN open, TX/RX frame IDs, decoded status, unknown frames, watchdog expiry, and motor faults. **Bring-up only** — revert to `scripts/env.example` defaults for normal bench. |
| Need position-hold motion debug | Set `MARENGO_POSITION_TRACE=/path/to/trace.csv` for high-rate CSV (side channel). Optional `berthier=debug` for onset burst logs. See [logging-taxonomy.md](logging-taxonomy.md). |
| Need live log-level changes from Consul | **Not implemented** (roadmap M5). Edit `RUST_LOG` in `/etc/marengo/env` and restart `marengo-pi` / `marengo-gateway`, or use per-crate overrides in `scripts/env.example`. |
| Need virtual CAN tests | Run `docker compose --profile vcan up -d vcan` or `just vcan` on Linux. This creates `vcan0`/`vcan1` only for tests. |
| vcan on macOS host | Use Linux container with `privileged: true`; SocketCAN is not available on macOS natively. |
| `modprobe vcan` fails in container | With `--network host`, the host must load vcan and create `vcan0`/`vcan1` first (`./scripts/ci-vcan-host-setup.sh` in CI, or `./scripts/vcan-up.sh` on Linux). Inside the container, `vcan-up` probes `ip link type vcan` when `/lib/modules` is missing — CAN tests still fail if vcan is unavailable. |

## Cross-compile (Pi / Jetson)

| Symptom | Fix |
|---|-----|
| `linker aarch64-linux-gnu-gcc not found` | On Mac: `./scripts/setup-mac-pi-cross.sh` then `just deploy-pi`. On Windows: `just deploy-pi-docker` (or `./scripts/deploy-pi-docker.sh`). |
| `cargo: command not found` in Docker deploy | Fixed: run through `./scripts/deploy-pi-docker.sh` (uses entrypoint + `PATH=/usr/local/cargo/bin`). Do not wrap in `bash -lc` manually. |
| `failed to get console: provided file is not a console` / `creating a console from a file is not supported on windows` / `The handle is invalid` | Docker `--ansi always`, `-t`, or `tty: true` on Windows PowerShell → Docker Desktop. `deploy-pi-docker.sh` uses plain `docker compose` + `-T`; `deploy-pi` service has no `tty:`. Progress via `CARGO_TERM_PROGRESS_WHEN=always`. |
| `exec format error` during `docker compose build` | Wrong platform image (e.g. arm64 on x64). Compose sets `platform: linux/amd64`; override with `DOCKER_PLATFORM=linux/arm64` on Apple Silicon if needed. |
| `can't find crate for std` / `target may not be installed` | Run `rustup target add aarch64-unknown-linux-gnu` once in the dev container, or use `deploy-pi-docker` / `ensure_pi_cross_target` in `deploy-pi.sh`. |
| `pi_build` / `pi_sync_main pi_native`: `cargo: command not found` on Pi | Install Rust on Pi or use cross deploy. MCP now sources `~/.cargo/env` and prepends `~/.cargo/bin` on SSH. |
| `deploy-pi.sh` / `buf` `ENOENT` on `downloaded-*-linux-x64-buf` | Host `consul/node_modules` from Windows npm inside Linux Docker — `deploy-pi.sh` re-runs `npm ci` when buf fails; prefer `just deploy-pi-docker` (uses Linux `consul-node-modules` volume). |
| Deploy re-downloads all crates every time | Bare `docker run -v .:/workspace` skips named volumes. Use `just deploy-pi-docker` only. First run ~2–5 min; incremental runs reuse `cargo-target` + `cargo-registry`. |
| Deploy shows no output / looks frozen | PowerShell pipes buffer Docker. Run `just deploy-pi-docker` unfiltered; set `MARENGO_DEPLOY_VERBOSE=1` for npm/cargo detail. Steps log as `==> [mm:ss] …`. |
| `Could not resolve hostname marengo.local` in Docker deploy | mDNS does not resolve inside the container. Set `MARENGO_PI_HOST` to a reachable name (e.g. Tailscale `joey-robot.tail….ts.net` or Pi IP) — same as `MARENGO_PI_HOST` in `.cursor/mcp.json`. |
| Cloud agent cannot reach Pi | Tailscale userspace mode required. Add secrets per [cloud-pi-tailscale.md](cloud-pi-tailscale.md); run `./scripts/setup-cloud-pi.sh --verify`. Use `./scripts/pi-remote.sh` instead of marengo-pi MCP. |
| `Permission denied (publickey)` in Docker deploy | Windows bind-mounts `~/.ssh` with loose permissions; `deploy-pi.sh` copies keys to `/tmp` with mode 600, prefers `id_ed25519_marengo`, and sets `IdentitiesOnly=yes`. If the mount is empty, Git Bash pathconv broke the `-v` bind — `deploy-pi-docker.sh` uses `//c/...` paths and `MSYS_NO_PATHCONV=1`. |
| Wrong glibc on device | Match Debian/bookworm-based images to Pi OS / JetPack versions. |

## Proto / Consul codegen

| Symptom | Fix |
|---|-----|
| TypeScript errors in `consul/` | `cd consul && npm run gen:proto` — never hand-edit `src/gen/`. |
| Rust build fails after `.proto` change | `cargo build -p armee-proto` regenerates via `prost-build`. |
| Checksum mismatch in CI | Regenerate TS (`npm run gen:proto`) and update `consul/src/gen/.checksum`. |
| Missing `.checksum` in CI | Run `npm run gen:proto` then `shasum -a 256 consul/src/gen/marengo/v1/marengo_pb.ts \| awk '{print $1}' > consul/src/gen/.checksum` and commit. |

## Simulation

| Symptom | Fix |
|---|-----|
| `check-sim` skipped | Run `docker compose --profile sim run --rm check-sim` (requires `Dockerfile.sim`). |
| MuJoCo model load fails | Verify `MARENGO_SIM_MODEL` points at `sim/fixtures/minimal.xml`. |

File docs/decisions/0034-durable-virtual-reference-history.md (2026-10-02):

# ADR 0034: durable virtual reference history without motion permission

Status: accepted, October 2, 2026. Software implementation qualified at b18faf4;
this decision creates no physical capability.

## Context

ADRs0023/0026/0027 leave genuine closed virtual reference evidence current only
after acquisition and all-address cleanup. They have no concrete journal or
owner-consumed durable completion. Acquisition terminals are immutable and
unusable. The coalescing configuration writer and telemetry Store cannot supply
the required reference event identity, retention and disk ordering.

## Decision

Implement R2b1 as a complete private producer, noncoalescing SQLite worker,
inspection/recovery reader and owner completion consumer. R2b2's explicit current
selected virtual grant follows separately. A durable row, copied database,
history object, public snapshot or startup never authorizes motion.

Only a specialized Unreferenced SimulationBus factory and matching ControlLoop
factory install a journal using explicit independent history/journal paths.
Resolve existing path ancestors before construction, refuse shared slots and
case-only aliases across the database and its `-journal`, `-wal` and `-shm`
namespace, and pin relative history paths to their original absolute
spelling. Compare existing files through the pinned portable file-identity
library too, so hard links cannot defeat independence. This read-only preflight
creates neither resource and opens no SQLite connection; the journal's existing
symlink/resource checks still run on its supplied spelling at lazy open.
Inspect existing resource types before identity opens. Nonregular history refuses
before YAML loading; only regular existing files enter the portable identity
comparison. Unsupported journal resources retain their lazy worker refusal.
Generic, physical and existing INITIAL constructors keep no journal I/O. The
worker opens lazily after accepted work; default owner shutdown remains a no-op
for absent journals. No public writer callback, evidence/completion constructor,
receipt importer, backend setter or grant method is introduced.

`begin_reference_commit` accepts an actual retained acquisition handle and
bounded operator/session audit text. It checks the latest still-current stage,
confirmation, complete successful cleanup and owner/realm/device/model/policy/
reference/stop continuity. It reserves one of eight credits before acceptance;
credits include queued, writing and completed-unconsumed work. QueueFull is
retryable before acceptance. Identical accepted retry returns its existing
handle; a conflicting audit body refuses. One accepted job per acquisition is
retained independently of acquisition outcome-cache rotation. Counter exhaustion
refuses before acceptance. Accepted failure or cancellation cannot renew the
stage or its original deadline.

Commit handles bind a private owner and checked sequence. A separate immutable
commit lifecycle, current eligibility and actual disk-result observation preserve
cancelled/expired/invalidated work even when its eventual disk write succeeds.
The existing acquisition terminal's `ReferenceCommit::Unavailable` is unchanged.
Eight completed owner outcomes are retained in addition to the eight reserved
completion slots; pending correlation is never evicted to admit other work.

Capture typed motors/control/homing at actual acquisition admission, beside the
existing bounded policy attestation. Retain the actual immutable installed
RobotConfigFile/URDF via a private borrowed descriptor accessor. Worker input
contains immutable data, not owner invalidation cells or current files. It
records virtual evidence class, acquisition/job/session identities, target and
address, original scalar widths and IEEE float bits, sign/confirmation/method/
offset policy, installed-model generation, the exact accepted f32 position,
actual raw-pop ordinal/CAN ID/device epoch, original deadline and stop/reference
continuity, complete cleanup/reporting attempts and receive summary. It does
not claim a complete original CAN packet or reconstruct private host causality.

Use an explicitly versioned binary field codec with primitive tags, bounded
strings/collections/depth and canonical ordered string-key maps. Serde directly
captures typed configuration; it never passes through JSON Value. Exhaustive
URDF field/variant projections preserve the pinned actual model. Decode and
canonical re-encode must match the original bytes, including numeric widths,
signed zero and subnormals. Nonfinite required values, unsupported tags,
oversize, duplicate/noncanonical fields and trailing data refuse. The encoded
body cap is 1MiB, not the obsolete 320KiB proposal; model/policy retention keeps
its existing 512KiB/256KiB bounds. Checksum is corruption evidence, not authority.
Complete independent numeric/field coverage precedes software qualification.

Use pinned rusqlite on a separate explicitly owned database. Refuse symlinked,
oversized, corrupt or incompatible resources without recreating them. Preserve
legitimate hot journals for SQLite recovery. Verify exact schema and pragmas;
reject incompatible persistent journal-format header versions through a bounded
read before SQLite can change a mode or create WAL sidecars. Supported rollback
files still let SQLite perform legitimate hot-journal recovery.
use DELETE journal, synchronous EXTRA, EXCLUSIVE locking after actual exclusive
access, zero busy timeout, 4096-byte pages and at most 16384 pages/4096 events.
Bound cache, SQL/blob lengths and rollback work separately. Disable cache spills
during each bounded transaction, so the pinned single-database pager needs one
sector header and at most 16384
old pages with eight bytes of record overhead each. Its 65536-byte sector cap
keeps this below the conservative 65MiB rollback limit; journal_size_limit is
only a retention setting. This is a pinned software resource bound, not media acceptance.
Allocate a checked persistent diagnostic session in a real transaction.
Event keys use session plus fixed-width unsigned job bytes. Equal key/body is
idempotent; conflicting bodies never replace history. Publish DurableHistory
only after successful transaction commit and exact identity/body/checksum
readback. Proven precommit failure and post-commit/commit-attempt uncertainty
remain distinct. Never purge, VACUUM or rotate history in the control owner.
SQLite's EXTRA adds DELETE-journal directory synchronization; its durability
still depends on VFS/filesystem/media behavior.
[SQLite pragmas](https://www.sqlite.org/pragma.html#pragma_synchronous),
[atomic commit assumptions](https://www.sqlite.org/atomiccommit.html).
The read/write format versions are defined by the
[SQLite file format](https://www.sqlite.org/fileformat.html#file_format_version_numbers).

Each explicit commit advance first performs the shared ordered disabled receive
drain, limited to 64 raw frames and 256 attempts. Whole-report hazards and the
original deadline at equality precede completion acceptance. Fresh checks use
the actual pinned stage even after cache rotation. Observed mismatch is sticky.
Pending eligible commit work inhibits ordinary intent and typed installation;
the real Berthier busy tick advances this owner and discards old intent without
a competing drain or MIT output. Cancellation retires eligibility immediately
and frees motion-busy state while accepted disk work keeps its credit. A later
matching completion may describe durable history but cannot restore eligibility.

Shutdown inhibits intent and cancels reference eligibility before mandatory live
acquisition cleanup or configured ordinary stop. Reuse actual acquisition
cleanup; unarmed journal failure invents no stop. Close both storage admissions
before either wait. One absolute budget covers both drains, with independent
stop, accepted/queued/in-flight/completed-unconsumed, failure/uncertainty and
observed thread-termination reports. Join only a finished worker. Timeout or
owner drop cannot cancel OS I/O; accepted work and truthful uncertainty survive
on the worker. Recovery remains history and every new owner stays Unhomed.

## Qualification

Keep all qualified acquisition, stamp/model, history-write, INITIAL and stop
probes unchanged. New APIs use genuine closed acquisitions and actual SQLite
transactions, independently decoded disk data and meaningful production mutants.
Exercise gates before actual open/commit and after commit/before publication,
eight accepted cancelled jobs with ninth refusal and credit return, real lock/
full/corrupt/schema/blocked-parent errors, idempotence/conflict, deadline equality,
peer hazards, model/policy change and late completion, worker unwind, bounded
shutdown and actual controller/Pi composition. Controlled child crashes distinguish
uncommitted rollback from committed unpublished history; they do not prove
power-loss acceptance. Release/join owned resources before decisive assertions.
Missing APIs, compilation and preparation errors are not behavioral reds.

Require independent Standards/Spec, primary gate, exact PR/main CI and native Pi
software qualification. CS05/CS06/CS07 remain partial until their full contracts
are proved. Physical firmware identity/reset/ack/readback, plant/timing/media,
support/sensors/E-stop, installed clients and current selected grant are separate.
No deployment, motor-limit increase, robot motion or Wave sign-off change is
included. Prompt before every physical movement; explicit owner confirmation
and commissioning are required. Ten-minute silence permits independent work only.

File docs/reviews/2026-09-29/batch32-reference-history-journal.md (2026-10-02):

# Batch32: durable virtual reference history software qualified

Preparation against merged main df468496eae0b3c30104874c3bc2b6ad218ec827,
on codex/reference-history-journal at
J:/code/marengo-worktrees/reference-history-journal. The candidate implements
the private R2b1 producer, exact-value codec, concrete SQLite worker, recovery
reader and owner completion consumer described in [ADR0034](../../decisions/0034-durable-virtual-reference-history.md).
Software qualification is complete at b18faf486073b7311a029761792be171dac457ef.
PR246 is delivered as main 1d855dfc45cdfe76da5f67d69beecf567bb4d301.
Final PR CI36990370708 and equal-tree main CI36991329746 pass all five jobs.
See the [delivery receipt](evidence/batch32/delivery-receipt.json) and
[source qualification](evidence/batch32/final-source-qualification.json).
CS05/CS06/CS07 remain partial; no physical acceptance is claimed.

Batch31 PR245 is delivered: final PR and equal-tree main each pass all five
CI jobs. Independent production and final metadata reviews are clear. Primary
and native Pi software qualification remain bound to dc88d283; native Pi passes
826 Rust tests (one existing ignored), 374 Consul tests and build/asset checks.
See the [delivery receipt](evidence/batch31/delivery-receipt.json).

The next WP04 dependency is a real bounded noncoalescing reference journal and
its owner-consumed durable history completion. R2b1 remains unusable for motion;
R2b2's selected current virtual grant follows. Read the
[preparation plan](evidence/batch32/preparation-plan.md), whose pending-main
sentence is historical and superseded by the delivered receipt. The
architecture ADR governs the journal, codec and lifecycle implementation.
Use complete committed Git archives for Pi staging, including simulation fixtures.

Focused candidate checks pass: changed-crate compilation, clippy with warnings
denied, all Davout/Berthier/Pi tests, and the new real SQL/controller/shutdown
cases. Coverage includes exact scalar widths/float bits and optional URDF fields,
durable readback, eight retained credits and retry after capacity refusal, actual
lock/full/corrupt/schema/session exhaustion, cancellation/deadline/peer hazards,
worker unwind and controlled child death before/after commit. Two child helper tests
do no work outside their explicitly launched child processes. These are candidate
conformance results, not original-binary behavioral reds or hardware acceptance.
Independent review of dc91d08 found two resource bugs: lexical-only history/journal
separation admitted aliases, and SQLite changed an incompatible WAL header before
refusing corrupt history. Separate real resource tests reproduced three behavioral
failures on that candidate (alias admission, worker mutation and inspection mutation).
The repairs resolve resource aliases before construction and reject unsupported
persistent header versions before SQLite opens the file. All four resource cases
now pass, including the distinct-path lazy-opening control. Three additional actual
owner tests cover a completed-unconsumed real write losing to fresh ordered fault
feedback, checked commit-counter exhaustion before admission and foreign-handle
refusal with healthy neighboring work. The original five new probe files and prior
qualified probes are unchanged. Changed-crate clippy remains clean.

Review of 0bebfae found a remaining SQLite sidecar collision. Two separate probes
reproduced admission through a canonical parent alias and actual deletion of an
existing valid calibration YAML when it occupied the rollback slot. Construction
now reserves the database and all three sidecars before any worker installation.
The preceding seven frozen probe files remain unchanged. The provisional 0bebfae
primary run was deliberately stopped before editing its source; it is not a gate
pass and its complete archive is retained. It was not uploaded or run on the Pi.

The subsequent 0dd5a2b review identified existing hard-link overlap. Real pinned
SQLite testing confirmed factory admission through the shared inode; the worker
completed a real second-session write while preserving the legacy YAML bytes.
This is an independence/admission failure, not demonstrated history corruption.
Construction now also compares existing file identity with already locked
same-file 1.0.6 and propagates identity I/O errors except genuine absence. The
eight preceding probe files remain unchanged. The obsolete 0dd5a2b primary was
stopped before edits; its archive was uploaded but never run or installed on Pi.

Review of a949ce4 identified a blocking identity open for named pipes. A bounded
child-process probe reproduced the construction stall and terminated/reaped its
owned child before reporting the behavioral failure. Type metadata now precedes
file identity opens: nonregular history refuses before YAML loading, while
unsupported journal resources preserve lazy worker refusal. The probe checks
all four journal slots and history, including actual worker failure for journal
slots. Its child helper is inert during ordinary test runs. All nine preceding
probe files remain unchanged; no a949ce4 final primary or native Pi run started.

The dc91d08 primary gate and native Pi software run passed (848 Rust tests, one
existing ignored, 374 Consul tests, build/asset checks and all 1764 committed input
hashes unchanged). Those results remain bound to the preceding candidate.
Final source b18faf4 passes the full primary gate and native Pi software run:
861 Rust tests, one existing ignored, 374 Consul tests, build/asset checks and
fatal primary ARM release. All 1769 committed staged inputs are unchanged before
and after native testing. All five source CI jobs pass in run36987033671.
Independent Standards and scoped Spec reviews are clear on this fixed source.

All ten new probe files and sixteen prior qualified files remain unchanged.
Twelve targeted production mutations each compile and fail their exact frozen
behavioral oracle; unmodified before/after runs pass 34 Davout, two Berthier and
one Pi shutdown tests. All 1769 isolated mutation-source files are restored.
The missing-COMMIT test's first result was incorrectly excluded by the runner's
inline-output parser because child output interrupted the test line. Its real
zero-versus-one-row assertion is preserved, and the same unchanged probe passed
mutation qualification on rerun after fixing only result recognition. Compile
and setup failures are never qualifying reds. No test-binary hash was captured.

The 35-test workspace increase includes two inert child helpers; these are not
35 independent hardware behaviors. The 4096 event bound is enforced but not
separately exhausted by a test; the real page-cap test qualifies SQLITE_FULL.
SQLite/process recovery tests establish no SD-card power-loss behavior. Final
documentation-head and equal-tree merged-main CI each pass all five jobs.

The owner requested right-arm movement validation and confirmed presence with
the arm resting at gravity home only. Read-only Pi observations show both CAN
interfaces up, installed services active and the cached safety state Disabled.
Legacy Verified joint flags do not qualify repaired current reference. Physical
support and live reference/client workflow remain unestablished. Prioritize the
remaining reference and installed-owner prerequisites, then propose a supported
single-joint direction test with explicit bounds, stop procedure and confirmation.
No motor command or physical CAN operation was issued by this qualification.

All 102 findings and eight maintenance tasks remain: 26 verified, 13 partial,
63 open. Existing CS05/CS06/CS07 statuses are unchanged. G06 lifecycle, T01/T02
activation, T03 generation identity and physical commissioning remain separate.

Installed Pi4bc77ba remains unchanged. No install, sudo, restart, physical CAN
operation or motor movement occurred. Gravity home does not establish support,
repaired current reference, E-stop or recovery. Prompt before every movement
with bounds and stop procedure; require explicit confirmation and commissioning
checks. Ten-minute silence allows independent work only. Preserve safety limits,
Wave sign-off, paused automation, CAD, branches and historical worktrees.

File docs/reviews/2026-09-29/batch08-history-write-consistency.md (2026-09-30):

# Eighth repair batch: historical rows after failed writes

Checked baseline: PR221 merge `1518176efd0561e60d3e23eee31c7bbe8ca84a2e`.
Active Windows checkout and CAD: `J:\code\marengo`.
Evidence: `J:/code/marengo-migration-backup-20260929/batch08`.
Status: two existing-public failures reproduced and repaired; both unchanged
replays pass; independent final reviews and strict affected checks pass; required
primary and all five implementation-head CI jobs pass in
[PR222](https://github.com/jaylamping/marengo/pull/222); final-head/equal-tree
main delivery and verified backup/branch cleanup are complete.

## Contract and scope

Baseline `HomingRegistry::record_verification` updates its public in-memory calibration
before writing the history resource. An actual write error therefore leaves an
uncommitted row visible, even though the method returns an error. Historical
publication must follow successful writing: preserve the previous record and
local state on failure, and permit a real later retry.

Stage a candidate historical record, write it through the existing filesystem
path, then publish it and perform the existing local state/flag transitions.
This is a small CS05 history-consistency subproblem. CS05 remains partial until
qualified acquisition, durable commit/private permission and installed-owner
clients are complete. Legacy local Verified is not Davout output permission.
In-place disk writing, partial writes, crash recovery and the new reference
journal remain separate work; write completion is not an fsync durability claim.
No hardware, master limits, CAD/model or Wave sign-off changes are included.

## Actual unchanged-production baseline

The independently reviewed existing-public probe compiles against an exact
archive of `1518176`, with all 1,432 original Git blobs verified and unchanged.
Its sole added integration test has SHA256
`3cc9aac2840cfefc75585637496c3ae08494ad0600b42a934e906ba7667c50d1`.
No production extraction or new API is used. Package cleaning and a compiled
manifest guard bind the actual archived crate; child-only temporary paths and
the native protoc tool stay under J:\code.

`original-red-v2.log` shows one intended assertion failure, Cargo 101, zero ignored
and 0.02 s test execution (1.985 s full run). A regular-file parent blocker causes
the actual typed Io error; the saved history is absent and blocker bytes survive,
but public calibration contains a new row. Actual writable neighbor, same-request
retry, independently decoded YAML, reconstruction with fresh Unhomed state and
exclusive cleanup all pass before the decisive assertion. The first launcher
attempt lacked protoc and executed zero tests; its preserved compile/setup
failure is excluded from behavioral evidence.

The second original-public probe freezes SHA256
`a69ae70c9edf585cbd485293a66b250e0f3da36b6ebaa47b47a0fb0f1fff8172`.
It first reaches a real prior successful write, then parks that exclusive
directory and installs a regular-file parent blocker. Typed Io preserves prior
parked/restored bytes and local state/flags, but memory wrongly replaces the
target row. Literal unrelated history, same-request successful retry, actual
YAML/reload and complete cleanup controls pass before the named assertion.
`replacement-red.log` has one failure, zero ignored, 0.02 s body and 2.597 s full;
all 1,432 original files plus the sole added probe are verified unchanged.

Only the existing registry writer changes: clone the record, stage its update,
write through the shared private writer, then publish memory and existing local
state/flag transitions. Public explicit persist uses the same filesystem path
and typed errors. Production registry SHA256:
`e59ed129418635f2b287a9dfb6c19837a2c11810124c8696fad1c6a62a9859b0`.

Both entire original probes pass byte-identically after this repair in separately
compiled frozen snapshots. Insertion: 1/0, 0.01 s body, 2.553 s full
(`candidate-green.log`). Replacement: 1/0, 0.02 s body, 1.352 s full
(`replacement-green.log`). All1,433 files in each snapshot remain unchanged
after execution, with only registry.rs differing from the original production.
The 287-input final compile/gate manifest binds actual source and both tests.

## Standards

No hard documented violation or blocker. One low possible duplication judgment
for manifest/YAML fixture setup is accepted to preserve frozen probe provenance.
The reviewer independently verifies all 287 source/gate identities and the exact
original archive. Receipt: `standards-review.md` under this batch's evidence root.

## Spec

No issue detected against the scoped historical publication contract. Both
original assertion failures and whole-file identical passing replays are
independently qualified, including all real failure/retry/reload/cleanup controls.
Receipt: `spec-review.md`. CS05 remains partial; no disk-crash durability, new
journal, current-reference grant or hardware acceptance is supplied.

## Required qualification

The identical insertion/replacement replays and independent reviews are complete.
Strict all-target Linux lint and affected homing/Davout/Berthier/Pi tests with
socketcan/linux-i2c pass 420/0, zero ignored (17.307 s full). The initial feature
selection omitted its provider package and executed zero tests; qualified v2
includes Pi and the preserved setup failure is excluded from behavioral proof.
Required primary passes 703 Rust/1 existing ignored, 355 frontend, 72 Pi MCP,
current deny/audit and the fatal aarch64 release build (101.223 s). Its immutable
per-run binding matches all 287 reviewed source/gate inputs. Evidence:
`primary-final` and `affected-linux-final-v2` logs/run JSON/source bindings,
reconciled by `local-gate-summary.json`. All five GitHub jobs pass at exact
implementation head `d541bd57a90f97417eda3d83981bcb7f74f54c0b` in
[run36736794717](https://github.com/jaylamping/marengo/actions/runs/36736794717):
703 Rust/1 existing ignored, 355 frontend, 72 Pi MCP, 5 simulation and 73 actual
virtual-CAN driver tests with none ignored. The committed 287-input manifest
matches local gates and both independently reviewed probes. Final documentation
head `7ddc243` passes all five jobs in run36738071460. Equal-tree merged
`04e4ea2` passes all five main jobs in run36738856051, including the fatal
aarch64 release build. External `merge-receipt.json` records the verified
all-ref backup and exact completed-branch cleanup, preserving all other refs. No new hardware-dependent
ignored test or sleep-based absence oracle is introduced. The known allowlisted paste maintenance warning remains M01.

## Reference continuation

The independently reviewed R2a-core proposal follows this bounded history repair:
target-only closed virtual acquisition/cancel/cleanup, ending EvidenceStaged with
CommitUnavailable and usable_reference=false. It writes no history and grants no
permission; ordinary physical adapters remain Unsupported. R2b supplies the real
recoverable noncoalescing writer and matching private grant installation; R3
supplies installed-owner clients. Those proposals remain unimplemented and their
acceptance tests unexecuted. Physical identity/reset/readback, drive limits/
timeouts, E-stop/support, model/plant and Wave requirements stay external.

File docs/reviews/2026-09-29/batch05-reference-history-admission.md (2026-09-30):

# Batch05: historical calibration and current reference

Baseline: merged main `6ff2ed82191d9e602aa230cedb80ae10259cce71` (PR217).
Branch: `codex/reference-history-admission`. Active checkout/CAD:
`J:\code\marengo`. Design:
[ADR0022](../../decisions/0022-calibration-history-and-current-reference.md).

Status: **R1a software slice verified on the implementation head; final evidence-head checks and safe merge required for delivery**. Review/delivery:
[PR218](https://github.com/jaylamping/marengo/pull/218). This report is
evidence of the bounded startup slice, not complete CS05 reference authority or
a physical commissioning procedure. The full 101 finding IDs and eight
maintenance tasks remain in the [ledger](implementation-ledger.json).

## Observable contract

Loading calibration history cannot grant current-process `Verified` state. Every
configured joint starts `Unhomed`, even when all recorded fields appear to match.
History remains inspectable and construction does not rewrite bytes. Only a
missing resource means empty history; other read failures and YAML parse errors
must be visible before Supervisor startup reporting transmits CAN traffic.

The homing library binds a deterministic supplied path. Supervisor composition
preserves the legacy environment override and provides an explicit-path entry
point using the same config/policy initialization. A relative override retains
its old process-working-directory meaning. Read errors do not fall back to an
empty record, and an explicit path wins over environment selection.

CLI help/refusal and Pi startup messages no longer recommend the former
fresh-process home/Enable recipe. Their command ownership remains unchanged.

## Baseline evidence

Before active production edits, replayed the existing-public tests in the exact
6ff archive with:

```text
cargo test --locked --no-fail-fast -p marengo-homing -p davout --test reference_history_baseline -- --nocapture
```

The command compiled and reached four behavioral assertion failures:

| Group | Independent expected behavior | Actual unchanged baseline |
|---|---|---|
| Apparently matching historical row | Retained history; Unhomed and not ready | Verified; `require_ready` succeeds |
| Five separate mismatches | Wrong device/interface/sign/position/revision cannot grant readiness | Every case Verified and ready |
| Malformed existing YAML | Construction returns a parse error and preserves bytes | Construction succeeds with empty history |
| Actual Supervisor, five historical rows | Checked home and normal Enable refuse; no Enable traffic | Home/Enable succeed, mode Active, five literal Enable IDs `0x0300fd01` through `0x0300fd05` |

The missing-file control passes: empty history, Unhomed, refusal and no file
creation. History byte-preservation assertions pass before the readiness
failure. No synthetic grant, unchecked home or missing-feedback failure is used
to manufacture the Supervisor regression. Each mismatch child executes before
the aggregate assertion; one early failure cannot hide later cases.

These are four groups, not nine distinct defects. Eight child behavioral
failures and one positive child execute. The two ignored parent dispatch workers
are explicitly invoked in children. Compilation/API absence is not a red result.
All 56 archived relevant production/config/model/proto/doc files match the exact
6ff Git blobs and retain their SHA256 after replay. Native compile 3.22s, whole
command 3.75s; crate test bodies 0.04s and 0.10s. No cross-host speedup is claimed.

Exact source, hashes, logs and fixtures:
`J:\code\marengo-migration-backup-20260929\batch05\reference-baseline-preparation`.
The archive is baseline evidence, not an active development checkout.

## Test replacement and qualification

The original two baseline test sources and support source pass byte-for-byte
unchanged against a separate candidate snapshot. All four previously failing
groups and missing/history-preservation controls pass; all nine children execute.
Only frozen homing/Davout source is overlaid onto the exact baseline archive;
56 candidate files remain unchanged during execution and all 56 original
baseline production hashes remain preserved. See
`batch05/existing-public-green/README.md` under the evidence root. This replay
uses the old public APIs and is independent of the new explicit-path API tests.

Active candidate integration tests add eight registry and four Supervisor parent
contracts. Registry tests cover exact/mismatched history, typed parse/IO failures,
missing resources, explicit binding, real persistence followed by reconstruction
refusal, and library environment independence. Supervisor tests cover historical
home/normal Enable refusal, missing history, zero startup TX on corrupt/directory
errors, and five child path-precedence cases. Child-only environment tests protect
absolute/relative explicit and legacy paths plus configured root-relative default.
No parent environment mutation or ignored/empty dispatch worker is added.

Two PID-sharing registry tests are replaced by missing-history and real
persist/reconstruct public contracts. The legacy verifier tests retain their
assertions with uniquely owned resources. One Davout global `set_var` test is
replaced by the explicit missing/history admission tests. Review also removed an
intermediate empty dispatch worker, preserving all five real child cases without
inflating the test inventory. No Cargo dependency or lock change is needed.

| Check | Result and scope |
|---|---|
| Required primary | Pass: 639 Rust, one existing ignored placeholder; 355 frontend; 72 Pi-MCP; eight vcan-setup and four dependency-gate contracts; strict lint/fmt/proto/build/deny/audit/index coverage; fatal main aarch64 release smoke |
| Affected Linux feature | Pass: 338 homing/Davout/Berthier tests, zero ignored; strict all-targets clippy with SocketCAN compiled |
| Native affected | Homing 29 tests and strict clippy pass. Davout's intermediate full 137 passed, then the dispatcher-only replacement passes four focused tests/strict clippy; final Linux integrated inventory is 136 Davout tests |
| Simulation | Pass: five tests and minimal.xml engine smoke (`nq=2`, `nv=2`); production plant qualification remains open |
| Independent review | Frozen code/contracts/runbook reviewed; no introduced blocker for the bounded R1a scope; exact receipt under batch05 evidence |
| Implementation-head GitHub | All five jobs pass at `8c3f62e933cb301d0800415b73674bcea7ad1af4`, [run36691835812](https://github.com/jaylamping/marengo/actions/runs/36691835812); actual outputs 639 check/one ignored, five sim/zero ignored, 73 driver feature/zero ignored |
| Final evidence-head GitHub | Required before merge; the followup changes review/evidence docs only. Actual final-head and merged-main jobs are preserved in the delivery receipt below |

Primary 98.79s, affected Linux 10.66s, simulation 2.71s. The original-test candidate
replay compiles in 6.85s and runs both test blocks in 0.11s (7.35s command wall
time). Compilation and test execution are distinct; no speedup is inferred from
different caches/hosts. One initial container launcher reset PATH before Cargo
could start; its log is preserved separately and does not count as a behavioral
test failure. The corrected non-login launcher passes. Primary keeps the known
Consul Router advisories (T31) and allowed unmaintained paste (M01) explicit;
software completion of those items is not claimed.

The implementation-head vCAN job executes all 73 driver feature tests, including
the six actual virtual-CAN cases and five Linux converters from batch04; it does
not certify physical firmware/reference. Source/test/operator guidance remains
identical after independent review and all local checks. The following evidence
commit updates the report, index, roadmap and ledger only, and still requires
all five successful exact-final-head checks before safe merge. The recoverable
bundle, actual final/main hashes, run/job identities, tree equality and cleanup
are preserved in `J:\code\marengo-migration-backup-20260929\batch05\merge-receipt.json`
after delivery and copied into tracked batch history in the next iteration.

## Remaining scope and physical acceptance

R1a does not make `record_verification`, public state setters, synthetic bench
grants, mutable registry access, unchecked Ready or direct scoped Enable safe
production authority. Cached Set Zero, target-only calibration, stop-before-disk,
immutable/recoverable persistence, owner/device/config/model identity, correlated
client receipts and taught-reference invalidation remain follow-up findings.
CS05 is **partial**: the startup software slice is verified on the implementation
head and awaits final evidence-head delivery checks; reference authority remains open.

Separate CLI Set Zero/home/Pi processes cannot recover readiness from saved
history. That former procedure is withdrawn in [homing.md](../../homing.md).
Fresh `motor-repl disable` constructs the full Supervisor before dispatch, so
corrupt history adds a concrete stop-dispatch failure trigger. The already
running Pi owner's Disable and `Supervisor::disable_all` do not reload history.
The required reference-independent stop and installed-owner caller cutover remain
CS07/CS09/T05/T12; no competing raw-CAN fallback is introduced. The fresh CLI is
not certified as emergency stop. Physical E-stop and arm support remain separate
acceptance requirements.

No physical robot connection, Enable, motion, flashing or deployment is part of
this batch. No torque/velocity ceiling or Wave sign-off change is authorized.

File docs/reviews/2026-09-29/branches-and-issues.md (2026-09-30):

# Branch PR and issue consolidation review

Audited on September 29, 2026 against main at **`4bc77ba605834fdec04b436daa4bec67bca84fbb`**. The evidence includes all fetched references, PR history and head OIDs, open PR/issue snapshots and comments, branch-tip contents, and the current implementation. The audit itself changed no refs, GitHub PRs/issues, production source, or robot state.

The detailed PR and issue tables describe their **open state at the audit baseline** and the review recommendations. The confirmed action ledger below records later consolidation; its status takes precedence over the baseline tables. The [repository review](../2026-09-29-repository-review.md) records the final consolidated outcome. Historical commissioning comments establish where work stopped, not today's hardware state.

## Confirmed consolidation actions

These actions were completed during the repository review. Retained branches are preserved recovery/design references; the linked GitHub records provide final CI and merge state.

| Item | Confirmed action | Remaining work |
|---|---|---|
| [PR #109](https://github.com/jaylamping/marengo/pull/109) | Closed as superseded; branch retained. | Useful rendering patterns remain available as design reference; F15 is unresolved. |
| [PR #117](https://github.com/jaylamping/marengo/pull/117) | Closed as superseded; branch retained. | Its glossary had already landed through PR #119. Readiness contract discrepancies remain review follow-up. |
| [PR #107](https://github.com/jaylamping/marengo/pull/107) | Reconciled against current main, independently reviewed and updated onto the verified maintenance baseline, with the final preservation ledger. | Final checks and merge state are on the linked PR record. |
| [Issue #118](https://github.com/jaylamping/marengo/issues/118) | Closed as implemented by PR #119. | Current findings and incomplete physical commissioning remain outstanding. |
| [Issue #115](https://github.com/jaylamping/marengo/issues/115) | Body updated with later #170 Reference/sign/quiet arm-down evidence and remaining elevated/ladder/Wave work; closed as superseded. | This closure does not establish full gravity-compensation or current-reference sign-off. |
| Historical PR #41 CAD payload | Retrieved from archived commit `1b31138`; size **1,707,374 bytes** and SHA256 **3e401d6748429e0015c359e072436f66e2a5dbc54d0180639b6e8d26a269fb65** verified. Preserved as a versioned historical CAD recovery record. | Current local bracket remains unchanged; no mechanical equivalence was inferred. |
| Other references and orphan features | No additional refs deleted and no orphan feature branch merged. | Follow the semantic verdicts below before any later cleanup. |
| Issues #96, #150, #170, #176 and #63 | Retained open. | Acceptance, commissioning and deferred feature work remain as described below. |

## Audit recommendations

- **Close PR #117 as superseded:** all nine added glossary rows are byte-for-byte present on main, absorbed by merged PR #119.
- **Close PR #109 as superseded prototype work:** shipped Hardware already has table-first/optional 3D, import/settings, facets, and scope. Preserve its design variants in the all-ref recovery bundle; production routes/packages already implement the chosen design.
- **PR #107 is useful only after rewriting its claims to match the implemented workflow.** Current URDF Accept promotes a disk file and requires restart, not arbitrary memory-first hot reload. Keep main's already-landed commissioning glossary.
- **Close issue #118 as implemented**, citing PR #119 and its historical verify report. Track current review defects separately; closing an implementation ticket does not declare the entire subsystem safe or physically commissioned.
- **Issue #115 can be closed as superseded narrowly by the later #170 Reference/sign/quiet GravityComp evidence**, with an explicit link to remaining elevated/ladder work. There is no new pass comment on #115 itself. Do not claim full G-comp sign-off.
- **Keep #96, #150, #170, #176, and #63 open.** #96 has an unaccepted end-to-end destination and documented runtime/persistence gaps; commissioning is incomplete; Wave remains locked; WebGPU is deferred.
- **Do not blindly merge the old Auto Learn branch or restore old CAD geometry.** It flips Wave true on outdated evidence and adds substantial new Pi service/proxy behavior. Closed PR #41 contains a unique historical **LFS pointer**. Its payload was initially absent from three inspected local caches and has now been retrieved and verified separately.
- **The initial 47 “merged via PR history” label hides four tip/head mismatches.** Two are already subsumed, but the other two contain genuine post-merge work that must be preserved/triaged before branch cleanup.

## Inventory and preservation limits

The supplied inventory contains 104 references: 40 ancestor-of-main, 47 merged-via-PR-history, four closed-unmerged, ten orphan, three open-PR. It includes the remote-default alias `origin`; that is not a normal feature branch to delete.

`marengo-all-refs.bundle` preserves the Git history/ref snapshots. It does **not** by itself preserve LFS binary bodies. Preserve the bundle, source/local CAD copies, this audit, and any fetched historical LFS payloads before removing references. A ref having a merged PR with the same branch name is insufficient evidence that its current tip was merged.

## Ten orphan branches

All seven research branches are documentation-only. Their files are absent from main, so their actual research text is unique, even when later issue resolutions/implementation absorbed conclusions. Several files still read as current instructions despite being dated snapshots; preserve and label/reconcile them before landing.

| Branch / tip | Semantic verdict | Safe action |
|---|---|---|
| `research/active-mit-modes-acceptance-gates` — `97caaef` | Useful August 11 inventory, superseded in important places: says TorqueOnly aliases GravityComp, says Disabled emits no batch, and links retired `docs/bench-*` suites. Main PR #166 implemented independent torque-command latching; Active+Disabled sends zero keepalives. | Preserve as historical research or refresh only this document with an explicit snapshot/superseded banner and links to the locked playbook. Do not promote its old mode table as current policy. |
| `research/actuator-velocity-baselines-24v` — `d3d341a` | Useful manual-source calculations and a reported protocol-scale discrepancy. Its advice to write 9.4/19.3/14.8 rad/s into live caps before the ladder contradicts the current locked playbook (`effective=min(% baseline, live safety ceiling)`, no safety-cap increase). Linear voltage scaling is expressly a proposed model, not a manufacturer guarantee. | Preserve calculations/source attribution; remove or clearly supersede the cap-raising instructions before merging. Keep physical baselines separate from actual legal command ceilings. Verify per-model/firmware MIT scales independently before changing the driver. |
| `research/harness-coverage-playbook-spine` — `1b17f9e` | Useful gap inventory: smoke scripts are not full commissioning gates. Contains old TorqueOnly-alias and profile/suite references. Current playbook still has TODO automation hooks, so much of the gap analysis remains relevant. | Preserve dated evidence; refresh terminology/links and alias claim if restoring into main. Do not equate smoke pass with chapter completion. |
| `research/limb-master-urdf-merge` — `5e6e8ad` | Historical design proposal; says no implementation exists, proposes memory-first hot reload, old bringup paths, and treats a negated axis as equivalent. Current `urdf_merge` and gateway import exist and differ: supported joint-field merging, disk promotion, restart-required. Negating axis changes coordinate semantics and cannot generally be declared harmless. | Preserve as a dated design proposal with a superseded-by-implementation note. Revise unsafe axis equivalence and current-status/hot-reload claims before using as an operational design doc. |
| `research/right-arm-taught-envelope-caps` — `5f37018` | Useful factual August 11 snapshot with provisional DOF5 and taught DOF1–4 values. Does not establish today's robot state. Includes an overstrong statement that velocity-only danger-zone clipping caps actual gravity descent; current zero-kd gravity mode does not produce braking from clipping an already-zero velocity setpoint. | Preserve unchanged numeric snapshot/provenance, explicitly label it historical, link current config/playbook and review finding CS14. Do not treat provisional firmware/sign/ROM as commissioned. |
| `research/urdf-pipeline-cad-to-pi` — `cc9a9f2` | Contains two useful August 9 research files. Many reported gaps have since changed: master 5-DOF, gateway URDF API/import/archive, master config cutover, and deploy preservation. Code/file links include retired paths. | Preserve both dated files; add current-status/retired-path notes or fold durable lessons into architecture docs. Avoid unedited merging of stale pipeline statements. |
| `research/urdf-v1-sim-completeness-fields` — `0505f2a` | **Exact duplicate final document contents** of the previous branch for both files (different commit histories). Blob IDs: pipeline `a56c2c44b672a2814d2908a62f930a061186bbea`, checklist `fd3f7a4dadf13c27854ebd3bd117e17d10f2d7df` on both tips. | Consolidate one copy of each file; retire the duplicate ref after preserving the bundle. No second merge is needed. |
| `prototype/hardware-page` — `3cfae48` | Throwaway A/B/C UI variants, explicitly labeled not production. Ancestor/earlier subset of open PR #109's prototype evolution; main now ships the chosen Hardware surface. | Archive design reference; retire without merging old prototype routes/package changes. |
| `prototype/limb-commissioning-playbook-stub` — `9b44cdf` | Explicit throwaway, “do not run as procedure yet.” Superseded by locked [docs/commissioning/limb-playbook.md](https://github.com/jaylamping/marengo/blob/4bc77ba605834fdec04b436daa4bec67bca84fbb/docs/commissioning/limb-playbook.md) from PR #169 plus later amendments; its baseline/caps wording is stale. | Archive or retain in historical reference, not as a second operational playbook. Retire branch after preservation. |
| `feat/auto-learn-pi-bff` — `a3d997b` | Genuine unmerged feature package: authenticated loopback proxy, Pi Node/service install, agent cwd changes, UI tokens/API/tests; also a cosmetic zero-icon commit and an old forearm mass/Wave unlock commit. Main has the earlier local-only Auto Learn tool, not this Pi proxy/service cutover. The branch sets `WAVE_POSE_GCOMP_SIGNED=true` based on retired E6 evidence and old pose/config; later #176 requires new live smoke and main flag is false. | Preserve full branch, reject bulk merge. Any desired proxy must become a fresh reviewed feature against current architecture/auth/deploy. Split cosmetics if still wanted after badge semantics are repaired. Do not cherry-pick the old model changes or Wave unlock. |

Research files are linked from closed issue resolutions/maps, so preserving their content in a clearly historical location is preferable to discarding them merely because there is no PR. If restored under `docs/research/wayfinder/`, repair relative links (many currently point one or two directories too shallow) and prominently link the current playbook; do not revive retired bench suites.

## Four closed-unmerged branch references

| Branch / PR / tip | Verdict and evidence | Safe action |
|---|---|---|
| `cursor/local-handoffs-disable-mem0-4f96` / [PR #57](https://github.com/jaylamping/marengo/pull/57) / `7b4eec6` | Old agent-memory policy and local handoff scaffolding, plus a Tailscale secret note. Main already has no mem0 server in its MCP configuration and no `docs/mem0-ops.md`/old memory rule; current instruction/skill layout moved further. Wholesale replay would restore stale agent instructions and removed artifacts. | Retire/archive as superseded policy. If the cloud Auth-key troubleshooting note remains useful, port that one sentence to current cloud docs separately; no full branch merge. |
| `feat/consul-actuator-harness-pr2` / [PR #42](https://github.com/jaylamping/marengo/pull/42) / `a5e8882` | Actuator command/session/allowlist foundation was implemented through later merged harness work. Current proto contains `ActuatorCommand`/tuning/session shapes, gateway actuator/session handling, and current command-joint allowlist; old bringup schema is obsolete. | Retire as superseded. Do not restore old proto/allowlist files over current master/commissioning code. |
| `feat/consul-actuator-harness-pr3` / [PR #44](https://github.com/jaylamping/marengo/pull/44) / `12d84da` | Pi overlay/GainOverride work landed through [PR #65](https://github.com/jaylamping/marengo/pull/65) (`d18535a`). Current [bins/marengo-pi/src/overlay.rs](https://github.com/jaylamping/marengo/blob/4bc77ba605834fdec04b436daa4bec67bca84fbb/bins/marengo-pi/src/overlay.rs) is the evolved implementation, including async persistence and live limit handling. Old branch includes PR #42 base changes too. | Retire as superseded; preserve only historical evidence. Its missing patch-ID equivalence is not proof it needs merging. |
| `fix/consul-chappe-deploy-pr5` / [PR #41](https://github.com/jaylamping/marengo/pull/41) / `351ca4f` | Deploy rebuild code already landed via PR #39/main `7d5c599`; old operator docs and mem0 refactor mostly obsolete. **Unique historical right shoulder-roll bracket revision exists**, but Git stores only its LFS pointer. | Do not merge branch wholesale. Recover/preserve historical CAD payload separately if obtainable, preserve pointer identity in this audit/bundle, and leave the newer live CAD file untouched. Refresh useful deploy triage docs against today's flow if needed. |

### Closed PR #41 CAD preservation detail

Path: `cad/parts/shoulder/marengo_shoulder_roll_bracket_right.SLDPRT`.

- Branch commit `1b31138` introduced Git blob `a1851035c8547ca7881a3972bef2003b67c7def0`, **132 bytes**: an LFS pointer.
- Pointer payload: SHA256 **`3e401d6748429e0015c359e072436f66e2a5dbc54d0180639b6e8d26a269fb65`**, size **1,707,374 bytes**.
- Previous tracked pointer (including commit `4c7b940`) targets `7ea94b6107e3257c72069d6f8d8cb7257d1bf1b586badc077c7668d70e6ddf10`, size 1,705,254 bytes.
- Current local J-drive part is **1,849,521 bytes**, SHA256 **`a9a7d098e93de8176d3ea1a67e1ee80f7aedd2914380545e2403b9916ad17f4d`**. It is distinct; no mechanical equivalence or superiority was inferred from size/hash.
- Historical payload `3e401…` was initially absent from inspected `.git/lfs/objects/3e/40/…` caches under J, C, and the retained WSL recovery source. `git-lfs/3.5.1` is installed. A Git bundle alone preserves the pointer, not that payload.

The historical payload has since been retrieved from commit `1b31138` and preserved in a versioned historical CAD recovery record, with its expected hash and size verified. The original branch remains retained. Do not replace the current bracket with the historical version or with the 132-byte pointer.

## Four merged-PR-name references whose tips moved afterward

These were discovered by comparing every merged-history branch SHA with recorded merged PR head OIDs.

| Reference | Recorded merged head vs current tip | Verdict |
|---|---|---|
| `cursor/robstride-firmware-modes-e0c4` | PR #1 head `bccf055` vs tip `85e965b` | **Unique post-merge docs:** commits `7d998d8`, `efbcc16`, `85e965b` add/evolve a Rudy retrospective and Marengo principles ADR plus roadmap link. The file is absent from main. Preserve it as historical design context; its ADR0006 number conflicts with current homing ADR0006 and its 4-DOF/“thin bins already enforced” claims are dated. Renumber/archive and annotate before landing, rather than replay old roadmap content. |
| `feat/yaw-suite-wave-teach` | PR #69 head `6029451` vs tip `92e0e51` | **Mixed later work:** 4-DOF profile addition exists in current history/master evolution; several Windows launcher/hook ideas were converted in PR #124/current TS launcher. But local-deploy-current-HEAD fix `3362971` is still missing on main: [tools/marengo-pi-mcp/src/tools/deploy.ts](https://github.com/jaylamping/marengo/blob/4bc77ba605834fdec04b436daa4bec67bca84fbb/tools/marengo-pi-mcp/src/tools/deploy.ts) local path currently fetches/checks out/pulls main, mutating the user's feature workspace. Preserve/port that behavior deliberately; main-only deployment can use an isolated checkout instead. Do not bulk replay old env/profile/launcher state. |
| `jl/limit-sync-opt-in-c19e` | PR #134 head `6781081` vs tip `304644b` | Post-merge removal of production loopback limit-sync URL is already on main via PR #135 `3571b94`; current `.env.production` contains no baked `VITE_LIMIT_SYNC_URL`. Safe to retire after backup. |
| `jl/set-limits-stale-refresh-551c` | PR #144 head `4bda20d` vs tip `ef2f69c` | Later exact-taught-hard/no-30mrad-pad patch is equivalent to main `8831744`; current [persist-joint-limits.ts](https://github.com/jaylamping/marengo/blob/4bc77ba605834fdec04b436daa4bec67bca84fbb/consul/src/lib/persist-joint-limits.ts) persists exact lower/upper and computes soft inset separately. Safe to retire after backup. |

The first two are not fully subsumed merely because a same-name PR merged. Their useful intent can be ported selectively or retained in the bundle with an explicit follow-up; no evidence supports dropping that distinction from cleanup accounting.

## Three PRs open at the audit baseline

### [PR #117 — actuator facets and Ready aggregation glossary](https://github.com/jaylamping/marengo/pull/117)

All nine new rows (`Actuator facets`, `Joint Ready`, `Limb Ready`, `Robot Ready`, `Commissioning scope`, `Hardware page`, `Telemetry page`, `Set Zero`, `Go-to-zero`) match main byte-for-byte. Issue #118's August 9 23:00Z comment explicitly says the glossary was absorbed into PR #119; PR #119 merged August 10 00:27Z. **Close as superseded**, citing PR #119. No rebase/merge is useful. Existing wording discrepancies with actual readiness aggregation can be fixed in the corrected consolidation glossary, not by merging this old draft again.

### [PR #109 — Hardware page 3D variants on vanilla Three.js](https://github.com/jaylamping/marengo/pull/109)

Development-only variants led to the production table-first Hardware design. Main route `/hardware`, [hardware-overview.tsx](https://github.com/jaylamping/marengo/blob/4bc77ba605834fdec04b436daa4bec67bca84fbb/consul/src/components/dashboard/hardware/hardware-overview.tsx), optional `Hardware3dView`, settings/import/scope components implement the selected product destination. Old `/prototype/hardware` UI variants and Bender figure remain reference material; adding them now revives dead route/package/chrome assumptions. **Close as superseded**, reference PR #112 (first Hardware SoT) and PR #119 (commissioning cutover), and preserve tip in the bundle. Visual polish remains separate deferred work.

### [PR #107 — Config/Setup URDF hydration glossary](https://github.com/jaylamping/marengo/pull/107)

It contains useful missing master/staging/archive/import vocabulary but incorrect present-tense claims:

- “Master Accept hot-reloads memory”, “incoming value becomes Active after 300–500ms”, and “persist-degraded Accept” describe an older unimplemented design. Current [hardware.rs:319-357](https://github.com/jaylamping/marengo/blob/4bc77ba605834fdec04b436daa4bec67bca84fbb/bins/marengo-gateway/src/hardware.rs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) archives/promotes disk and `:384` says restart required; Pi caches its model at construction.
- “Hardware's primary chrome is interactive 3D” / “Subsystems durable counterpart” are superseded by table-first Hardware and read-only Telemetry.
- “Git only bootstraps and cannot clobber divergent files” is an intended policy, not an unconditional current deploy guarantee.
- “All mapped link inertial fields merge” overstates the implemented joint-field merge projection.

**Recommended action:** rewrite PR #107 from current main with only corrected glossary additions/replacements, retain current session/commissioning rows, update its title/body to the actual final scope, verify doc links/diff, then merge normally. Do not merge the old branch verbatim.

## Seven issues open at the audit baseline

| Issue | Evidence and present status | Recommended action |
|---|---|---|
| [#118 — Hardware commissioning + Consul master chrome cutover](https://github.com/jaylamping/marengo/issues/118) | Main contains merged PR #119 `9a7894e`; PR #120 review fixes merged into its branch first. [openspec/changes/consul-hardware-commissioning/verify-report.md](https://github.com/jaylamping/marengo/blob/4bc77ba605834fdec04b436daa4bec67bca84fbb/openspec/changes/consul-hardware-commissioning/verify-report.md) records 34/34 applied, Consul 288+workspace tests at the time, PASS WITH WARNINGS; physical smoke deferred to #115. Implementation/facets/scope/routes/glossary are visibly present. | **Close as implemented** with PR #119. Archive the lingering OpenSpec change when consolidating docs, retaining historical warnings. Current defects get linked repair tickets, not erased by this closure. |
| [#115 — Re-zero yaw/elbow and re-run gravity smoke](https://github.com/jaylamping/marengo/issues/115) | The issue only has the old blocked-on118 comment. Later #170 records Reference PASS at 23:28Z on August 11, all five sign checks, and quiet arm-down GComp session 001113Z with Active/residual PASS. Later float and elevated sessions expose additional issues. | **Close as superseded narrowly** by170 if cleaning duplicates: link later Reference/sign/quiet GComp evidence, transfer any unresolved gravity behavior to170/repair backlog. Do not say coupled elevated GComp is commissioned or today's zero is valid. Keeping it until that cross-link is written is also defensible. |
| [#96 — Consul Hardware/URDF SoT map](https://github.com/jaylamping/marengo/issues/96) | Software destination mostly shipped via PRs #112/#119, but original #114 smoke failed; no final explicit destination acceptance was found. The promised Accept=immediate-memory-active contract differs from current restart-required import. Current review finds persistence, import, reference, and auto-rearm defects. | **Keep open**, update its execution status and unresolved gaps; close only with a recorded destination acceptance or explicit rescope separating shipped UI from remaining contracts. Do not infer physical acceptance from unit tests or PR #119 merge. |
| [#150 — Limb commissioning playbook map](https://github.com/jaylamping/marengo/issues/150) | Locked playbook169, TorqueOnly166, params171, Wave175/179 are shipped. The map also includes execution of the right arm to full signed-off usable state.#170's execution stops midway through the 50% ladder and chapters 6–9 are unfinished. | **Keep open.** Record authored procedure vs incomplete physical execution separately. |
| [#170 — Execute right_arm through locked limb playbook](https://github.com/jaylamping/marengo/issues/170) | 58 historical comments. Reference/limits/sign passed; arm-down/mid/float had qualified passes; elevated was NOT GREEN; §4c was PASS with notes while violating the strict dwell criterion; 25% ladder passed,50% failed the roll return, later retry incomplete. No final limb/payload/mode sign-off. | **Keep open**, resume only after current safety review repairs/reassessment and operator support. Link exact stop point and qualified GComp debt. Do not flatten “Ch1–4done” into rigorous complete acceptance. |
| [#176 — Live Wave smoke then flip WAVE_POSE_GCOMP_SIGNED](https://github.com/jaylamping/marengo/issues/176) | Main [consul/src/data/compound-tests.ts:65](https://github.com/jaylamping/marengo/blob/4bc77ba605834fdec04b436daa4bec67bca84fbb/consul/src/data/compound-tests.ts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) remains false.#170 §4c comment explicitly keeps false pending documented live raise+elbow-wave smoke. Original issue pose/extrema are outdated after PR #179, while current playbook requires both §4c and new live smoke. | **Keep open and flag false**. Update expected pose/range/rev to current playbook before execution. No merge or backlog tidy-up can substitute for the operator/hardware evidence. |
| [#63 — WebGPURenderer](https://github.com/jaylamping/marengo/issues/63) | Explicitly deferred and conditional on measured CPU/battery/scene wins. No WebGPU/WebGPURenderer/three-webgpu implementation found in current `consul/src` or package configuration. | **Keep open as future work**, optionally label deferred. No reason to merge unrelated prototypes or treat it as a current correctness bug. |

## Last recorded robot session: exact evidence and limits

All times below are **UTC from historical issue comments**. No present robot state was inspected. Key #170 records:

1. **2026-08-11 23:28:38Z:** Reference PASS; operator confirmed Homing Verified/JointReady/fault=0.
2. **2026-08-12 00:19:44Z:** arm-down per-joint GComp PASS with notes; quiet residual session 001113Z passed, float session 001752Z exceeded upper-yaw hard limit.
3. **01:01:08Z:** elevated attempt 005812Z survived but drift failed: pitch−.105rad, yaw+.164, elbow+.413; elevated not green.
4. **01:31:08Z:** wave_pose session 012649Z PASS-with-notes; pitch+.076rad violates the <0.05 rad criterion, residuals soft, operator accepted a checkpoint; Wave flag explicitly false.
5. **03:06/03:07Z:** 25% ladder session 030430Z PASS/ok_candidate using comfort cruise overrides and PR #181; 129 ascent-breakaway trace events noted as jerky.
6. **04:02:56Z:** 50% session 040100Z on `4bc77ba` fixed pitch hang; roll 1.40→0.20 rad failed because target envelope-clamped to approximately 0.382 rad and runner settle timed out.
7. **04:04:37Z:** 040257Z retry stopped midrun, explicitly incomplete/do-not-score; planresume50%steppedroll, then75/100,near-limit,chapters 6–9.
8. **04:07:57Z, latest comment:** **remote stop was NOT confirmed** after Tailscale loss. This supersedes the prior “Stopped safely” claim. No current robot state was inspected in this audit; do not report it as safely stopped or active now.

These records are helpful for reconstructing where the user left off, but historical operator checkpoints do not prove a currently powered robot's reference, safety state, or acceptance.

## Recommended consolidation sequence

1. Retain Git bundle/local recovery/CAD manifests, recover any unique LFS body or explicitly record its absence.
2. Close superseded PRs #117/#109; rewrite useful PR #107 terms from current implementation and merge after review/checks.
3. Close #118 as implemented; narrowly cross-link and close #115 as superseded if desired; leave #96/#150/#170/#176/#63 open with accurate status.
4. Preserve/refresh historical research text; consolidate the two identical pipeline/checklist histories; retire throwaway prototypes.
5. Extract genuine post-merge design/deploy intent from the two mismatched tips; do not merge old branches wholesale. Reclassify those tips accurately in the cleanup ledger.
6. Retire already-subsumed branch refs only after recorded preservation; mark substantial AutoLearn feature as archived/deferred and do not carry its old Wave unlock or model into main.
7. Keep all safety fixes and physical commissioning as separate concrete follow-up work. Documentation cleanup does not satisfy the incomplete hardware gates.

## Legacy Windows branches worktrees and stashes

A final read-only check covered both `marengo.DEAD` recovery sources: the older C-drive checkout and its J-drive copy. Both are on legacy main `51a248af244eb382e144db9ef6bfa59a9b37ce8e`. They contain identical sets of **90 refs: 29 local branches, 40 remote refs, 20 checkpoint refs and the latest stash ref**, plus **23 stash entries** in reflog history. This local inventory is separate from the 104-reference GitHub inventory above.

Every ref was compared with current J-drive refs/main and both earlier migration bundles. **Four local branches contain eight commits absent from those prior preserved histories**. The table below records all 29 local tips. A branch having no new commit does not by itself prove its changes landed on main; the main-ancestor column and semantic verdict distinguish those cases. Full source-specific refs and commit comparisons are retained in the local recovery records.

The two sources now have separate verified bundles containing all refs and reflog history, source-specific staged/working patches and metadata, and readable recovery copies. **Three physical A/B/C worktrees per source contributed 2,456 files / 128,078,906 bytes**, excluding only encountered `consul/node_modules` caches. All 4,912 copies passed SHA256 comparison; matching source-specific manifests confirm the C/J worktree copies are identical. Their modified tracked and untracked UI files are preserved. **440 LFS-cache files / 1,045,184,082 bytes** are preserved once under J with verified source-specific manifests; both caches match. The deleted `.slim/codemap.json` state and its original blob are also preserved.

No legacy source was deleted, moved, repaired, checked out to another branch, or used to issue a robot command. Recovery artifacts live in the migration backup's `legacy-windows-state` folder, with a recovery README and verification manifests.

### All local branch tips

| Branch | Legacy tip | Ancestor of reviewed current main | New commits absent from current refs and prior bundles | Verdict |
|---|---|---|---|---|
| `bench-700g-com-calibration` | `aec003558a` | No | 3 | Historical single-joint 700 g COM calibration; archive fixture evidence, do not replace current master. |
| `clear-glider` | `3a87be28a1` | Yes | 0 | Already included in main ancestry; preserve as historical reference. |
| `consul-glinui-dashboard` | `094e65860b` | No | 1 | Historical weighted-arm remediation notes and old context-split skill; selectively archive docs, leave old agent policy retired. |
| `consul-glinui-linear` | `995a6fff1b` | Yes | 0 | Already included in main ancestry; preserve as historical reference. |
| `consul-glinui-pr1-base` | `ec847a5f00` | Yes | 0 | Already included in main ancestry; preserve as historical reference. |
| `consul-glinui-pr8-cleanup` | `a40cc6e4ac` | No | 3 | Radix-only UI cleanup/lint gate already present in main; glass/contrast styling superseded by current panel design. Archive. |
| `cursor/robstride-can-readiness-c935` | `d24e0b0081` | Yes | 0 | Already included in main ancestry; preserve as historical reference. |
| `feat/can-loop-diagnostics` | `c3b2c9859b` | Yes | 0 | Already included in main ancestry; preserve as historical reference. |
| `feat/consul-actuator-harness-pr1` | `a03be99eba` | Yes | 0 | Already included in main ancestry; preserve as historical reference. |
| `feat/consul-actuator-harness-pr2` | `a5e8882131` | No | 0 | Old actuator command/allowlist foundation superseded by later main implementation; archive. |
| `feat/consul-actuator-harness-pr3` | `12d84da003` | No | 0 | Old Pi overlay/gain foundation superseded by evolved main overlay; archive. |
| `feat/consul-actuator-harness-pr4` | `924d7c13c7` | No | 1 | Unique checkpoint changes bracket LFS pointer to the verified PR41 payload. Preserve CAD history; actuator work evolved on main. |
| `feat/rs03-p1a-recv-poll` | `27427f4485` | No | 0 | Receive-poll/watchdog separation exists in current implementation; retain archived fork, repair CS01 in current code. |
| `feat/rs03-p1b-type24` | `3b20f8c703` | No | 0 | Type24 active-reporting intent is implemented and evolved into sensing leases; retain archived fork. |
| `feat/rs03-p1c-params` | `778eb227aa` | No | 0 | Parameter-ID audit variants exist in current driver; actual safety timeout/limit handshake remains current review work. |
| `feat/subsystems-set-limits` | `bc60e268e1` | Yes | 0 | Already included in main ancestry; preserve as historical reference. |
| `feat/yaw-suite-wave-teach` | `92e0e51cb3` | No | 0 | Existing post-merge deploy-current-HEAD intent remains useful; use earlier branch verdict, preserve and port selectively. |
| `fix/consul-chappe-deploy-pr1` | `6a32208abc` | Yes | 0 | Already included in main ancestry; preserve as historical reference. |
| `fix/consul-chappe-deploy-pr2` | `fd2923bba7` | Yes | 0 | Already included in main ancestry; preserve as historical reference. |
| `fix/consul-chappe-deploy-pr3` | `bad7754924` | No | 0 | Always-rebuild deploy intent landed through later merge; archive the older local commit. |
| `fix/consul-chappe-deploy-pr4` | `2ca4e4b317` | Yes | 0 | Already included in main ancestry; preserve as historical reference. |
| `fix/consul-chappe-deploy-pr5` | `351ca4faad` | No | 0 | Existing PR41 verdict applies; current deploy evolved and historical CAD payload has been recovered. |
| `gravity-comp-enhancement` | `00fa690f56` | Yes | 0 | Already included in main ancestry; preserve as historical reference. |
| `main` | `51a248af24` | Yes | 0 | Already included in main ancestry; preserve as historical reference. |
| `majestic-helicona` | `ad66706140` | Yes | 0 | Already included in main ancestry; preserve as historical reference. |
| `pi-bench-urdf-sync-tool` | `2714d776d1` | Yes | 0 | Already included in main ancestry; preserve as historical reference. |
| `redesign/consul-a` | `e01a540534` | Yes | 0 | Already included in main ancestry; preserve as historical reference. |
| `redesign/consul-b` | `e01a540534` | Yes | 0 | Already included in main ancestry; preserve as historical reference. |
| `redesign/consul-c` | `e01a540534` | Yes | 0 | Already included in main ancestry; preserve as historical reference. |

### Unique local branch content

- `bench-700g-com-calibration` adds three June 19 commits (`3b53318`, `a5d6604`, `aec0035`) tuning COM in the old single-joint weighted URDF fixtures and limiting the change to assets. It is evidence for that historical fixture, not calibration of today's five-DOF master. Preserve the measured-history context and assets; do not merge its old geometry into current master.
- `consul-glinui-dashboard` adds checkpoint `094e658`: a weighted 700 g remediation document and old context-split agent skill. The document discusses COM/friction/feedforward and obsolete direct deploy/WSL paths. Archive it as historical reasoning, with a current-status banner if later published. Do not revive its old operational procedure or agent policy.
- `consul-glinui-pr8-cleanup` adds three commits (`169fe3a`, `575a16d`, `a40cc6e`) for sidebar contrast, Base UI removal/Radix lint gating, and glass-card pointer styling. Main already contains the Radix lint gate and no Base UI dependency; current cards use the evolved panel design. The unique commit IDs do not establish a missing production capability. Archive this fork; any visual idea needs a small current-code patch.
- `feat/consul-actuator-harness-pr4` adds checkpoint `924d7c1`, changing the shoulder-roll bracket pointer to SHA256 `3e401d6748429e0015c359e072436f66e2a5dbc54d0180639b6e8d26a269fb65`, size 1,707,374 bytes. This is the same historical PR41 body already recovered and verified. Preserve the version; do not replace the current bracket or merge old actuator/overlay state over current code.

### Uncommitted UI worktrees

All three physical worktrees start from `e01a54053497cad36830010775aea4c53763bd23`. Their original `.git` pointers/registrations still refer to pre-rename paths; the review read them through their preserved administrative gitdirs without repairing the sources.

| Worktree | Preserved differences | Recommended disposition |
|---|---|---|
| `consul-a` | Modified usage-bar plus untracked rail navigation/user-menu and console panel/metric components. | Archive as an A variant; no live hardware capability or current commissioning fix established. |
| `consul-b` | Dependency locks/package, usage-bar, button/card/slider and global CSS changes; untracked flight figure header. | Archive as a B variant; dependency/style changes need independent current-code review before reuse. |
| `consul-c` | Global CSS changes plus untracked machine-state chrome and UI store. | Archive as a C variant; mock/local machine-state presentation must not replace authoritative telemetry. |

`clear-glider` and `majestic-helicona` still have administrative registrations but their `.kilo` working directories are absent from both sources. Their branch commits and administrative metadata, including empty staged diffs, are preserved; no missing uncommitted or untracked working files can be reconstructed from a directory that is absent. Their commits are already in current main ancestry.

### Checkpoint snapshots

The **20 parentless checkpoint commits** represent **two unique file trees**: five snapshots use `17d627273f9b81515dd0666cfa849c97c6721ca3`, and fifteen use `4342f34a6b93c50ad81222ff98d943214ab49dba`. Within each tree group, the snapshot contents are identical. The later tree adds/evolves the old mem0 agent integration, policies and vendored dependency state. Both are whole historical workspace snapshots containing older UI/control/config and generated dependency data, rather than focused feature commits with a normal branch ancestry.

They are preserved in the bundles with exact ref/OID inventories and patches against legacy main. Archive them; do not merge a parentless workspace snapshot into today's master. Selective recovery of a needed historical file remains possible without restoring obsolete profiles, memory policy, old source paths or dependency caches.

### Historical stash records

All **23 stashes**, including tracked/index and available untracked parents, have patches, parent identities and readable file recovery with SHA256 manifests. These are dated May through July 2026. Historical CAD blobs/pointers are preserved alongside the LFS caches; current geometry stays unchanged. The dispositions below are semantic archival decisions, not claims that every old experimental patch was runtime-tested or mechanically validated.

| Stash commit | Content and recommended disposition |
|---|---|
| `16cf538` | Subsystems dependency lock backup; preserve for provenance, avoid replaying obsolete dependency resolution. |
| `b087df6` | Old WSL-to-Windows MCP/ignore changes; archive, use the accepted J-drive development policy. |
| `32a1f58` | UI glass/space-backdrop experiment, textures and component tests; archive as visual design reference. |
| `d772948` | Two-DOF setpoint/trace/harness WIP; compare any useful intent against current lead/stall control, never import old gains/config wholesale. |
| `8418b6d` | Gateway config/store/proto/admin WIP; current master/limits APIs evolved, preserve and use current transaction fixes. |
| `c1dcc96` | Old agent-persona policy; archive rather than restore retired instruction layout. |
| `f1e6a8f` | Old dual-shoulder motor map; archive hardware history, do not apply old motor IDs/signs. |
| `01d9983` | Historical shoulder bracket CAD; preserve version independently of current model. |
| `d3006c7` | Old actuator tuning/rate-limit WIP plus bracket CAD; implementation superseded, preserve historical CAD. |
| `5e0e685` | Mixed actuator/overlay/proto WIP plus CAD; archive, avoid replacing evolved control/commissioning contracts. |
| `d889b66` | Historical bracket CAD backup; preserve independently of current model. |
| `6a5bb7e` | Mixed glass Overview WIP and CAD; archive design/CAD evidence, do not replay test deletions. |
| `f35ace9` | Old logs/memory UI WIP; archive, use current log reliability fixes and retired-memory policy. |
| `2d1fb6c` | Mixed logs/memory/sidebar WIP plus CAD; archive, salvage only a deliberately reviewed isolated idea. |
| `c21429f` | Old Overview card/skeleton tests and styles; current UI evolved, preserve design/test provenance. |
| `907a6f2` | Historical right-arm and torso CAD assemblies; preserve versions separately. |
| `1a010fd` | CAD assembly/naming WIP and debug artifact; preserve historical CAD, do not replace current model. |
| `22db1f1` | Left-only overshoot/control/motor-map backup; archive old bench setup, do not apply current-arm gains or mapping from it. |
| `e29a273` | Pi MCP lockfile backup; preserve provenance, avoid old dependency downgrade. |
| `fb6fb59` | Early Chappe/telemetry/host-metrics/deploy WIP; current stack evolved, archive and repair present findings directly. |
| `1e3a96d` | Historical Pi commissioning notes; preserve as a dated record, not the current locked procedure. |
| `b85ba73` | Early CAN/bin dependency WIP; current driver/runtime supersede it, preserve history. |
| `1d44d1a` | Historical torso-frame CAD assembly; preserve version independently. |

### Preservation limits

Git bundles preserve commits and LFS pointers; the verified cache copy preserves all LFS files physically present in these two sources. This does not establish that every historical pointer ever recorded in remote history has a locally available body. The known PR41 gap was explicitly fetched and verified. No CAD geometry, mass, center of mass, firmware setting or present robot reference was validated by these recovery operations.

The missing `.kilo` working directories remain an explicit recovery limit. Cache exclusions were restricted to encountered regenerable node_modules directories in the physical worktrees; all encountered noncache local files, including URDF fixtures and visual artifacts, were copied. The original DEAD directories remain recovery sources. No additional feature branch was merged or deleted as part of this preservation pass.

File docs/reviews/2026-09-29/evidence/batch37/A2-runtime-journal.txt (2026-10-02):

Oct 02 11:10:10 marengo systemd[1]: Stopping marengo-pi.service - Marengo Pi runtime (control, CAN, Chappe)...
Oct 02 11:10:10 marengo marengo-pi[643420]: 2026-10-02T16:10:10.424517Z  INFO marengo_pi: shutdown stop delivery evidence; physical stop unconfirmed writes_accepted=true report=Some(StopReport { generation: 1, attempts: [StopAttempt { address: MotorAddress { interface: "can0", device_id: 1 }, action: ZeroSpeed, error: None }, StopAttempt { address: MotorAddress { interface: "can0", device_id: 1 }, action: NeutralMit, error: None }, StopAttempt { address: MotorAddress { interface: "can0", device_id: 1 }, action: Disable, error: None }, StopAttempt { address: MotorAddress { interface: "can0", device_id: 2 }, action: ZeroSpeed, error: None }, StopAttempt { address: MotorAddress { interface: "can0", device_id: 2 }, action: NeutralMit, error: None }, StopAttempt { address: MotorAddress { interface: "can0", device_id: 2 }, action: Disable, error: None }, StopAttempt { address: MotorAddress { interface: "can0", device_id: 3 }, action: ZeroSpeed, error: None }, StopAttempt { address: MotorAddress { interface: "can0", device_id: 3 }, action: NeutralMit, error: None }, StopAttempt { address: MotorAddress { interface: "can0", device_id: 3 }, action: Disable, error: None }, StopAttempt { address: MotorAddress { interface: "can0", device_id: 4 }, action: ZeroSpeed, error: None }, StopAttempt { address: MotorAddress { interface: "can0", device_id: 4 }, action: NeutralMit, error: None }, StopAttempt { address: MotorAddress { interface: "can0", device_id: 4 }, action: Disable, error: None }, StopAttempt { address: MotorAddress { interface: "can0", device_id: 5 }, action: ZeroSpeed, error: None }, StopAttempt { address: MotorAddress { interface: "can0", device_id: 5 }, action: NeutralMit, error: None }, StopAttempt { address: MotorAddress { interface: "can0", device_id: 5 }, action: Disable, error: None }] })
Oct 02 11:10:10 marengo marengo-pi[643420]: 2026-10-02T16:10:10.424571Z  INFO marengo_pi: owner shutdown outcome persist_idle=true status=Complete successful_requests=0 failed_requests=0 publication_failures=0 pending_requests=0 in_flight=false worker_terminated=true worker_error=None coalesced_requests=0 reference_journal=ReferenceJournalDrain { admission_closed: true, queued: 0, in_flight: false, completed_unconsumed: 0, accepted_credits: 0, durable_writes: 0, failed_writes: 0, uncertain_writes: 0, worker_terminated: true, worker_error: None } outcome=ShutdownOutcome { persist_idle: true, stop: Attempted { result: Ok(()), report: Some(StopReport { generation: 1, attempts: [StopAttempt { address: MotorAddress { interface: "can0", device_id: 1 }, action: ZeroSpeed, error: None }, StopAttempt { address: MotorAddress { interface: "can0", device_id: 1 }, action: NeutralMit, error: None }, StopAttempt { address: MotorAddress { interface: "can0", device_id: 1 }, action: Disable, error: None }, StopAttempt { address: MotorAddress { interface: "can0", device_id: 2 }, action: ZeroSpeed, error: None }, StopAttempt { address: MotorAddress { interface: "can0", device_id: 2 }, action: NeutralMit, error: None }, StopAttempt { address: MotorAddress { interface: "can0", device_id: 2 }, action: Disable, error: None }, StopAttempt { address: MotorAddress { interface: "can0", device_id: 3 }, action: ZeroSpeed, error: None }, StopAttempt { address: MotorAddress { interface: "can0", device_id: 3 }, action: NeutralMit, error: None }, StopAttempt { address: MotorAddress { interface: "can0", device_id: 3 }, action: Disable, error: None }, StopAttempt { address: MotorAddress { interface: "can0", device_id: 4 }, action: ZeroSpeed, error: None }, StopAttempt { address: MotorAddress { interface: "can0", device_id: 4 }, action: NeutralMit, error: None }, StopAttempt { address: MotorAddress { interface: "can0", device_id: 4 }, action: Disable, error: None }, StopAttempt { address: MotorAddress { interface: "can0", device_id: 5 }, action: ZeroSpeed, error: None }, StopAttempt { address: MotorAddress { interface: "can0", device_id: 5 }, action: NeutralMit, error: None }, StopAttempt { address: MotorAddress { interface: "can0", device_id: 5 }, action: Disable, error: None }] }) }, mandatory_reference: None, persist: PersistDrainReport { status: Complete, successful_writes: 0, failed_writes: 0, publication_failures: 0, pending_requests: 0, in_flight: false, worker_terminated: true, worker_error: None, coalesced_requests: 0 }, reference_journal: ReferenceJournalDrain { admission_closed: true, queued: 0, in_flight: false, completed_unconsumed: 0, accepted_credits: 0, durable_writes: 0, failed_writes: 0, uncertain_writes: 0, worker_terminated: true, worker_error: None } }
Oct 02 11:10:10 marengo marengo-pi[643420]: 2026-10-02T16:10:10.424666Z  INFO marengo_pi: marengo-pi stopped
Oct 02 11:10:10 marengo systemd[1]: marengo-pi.service: Deactivated successfully.
Oct 02 11:10:10 marengo systemd[1]: Stopped marengo-pi.service - Marengo Pi runtime (control, CAN, Chappe).
Oct 02 11:10:10 marengo systemd[1]: marengo-pi.service: Consumed 2.214s CPU time.
Oct 02 11:10:10 marengo systemd[1]: Started marengo-pi.service - Marengo Pi runtime (control, CAN, Chappe).
Oct 02 11:10:10 marengo marengo-pi[643903]: 2026-10-02T16:10:10.515013Z  INFO marengo_pi: Chappe IPC fanout enabled path=/run/marengo/chappe.sock
Oct 02 11:10:10 marengo marengo-pi[643903]: 2026-10-02T16:10:10.515406Z  INFO marengo_pi::imu: starting IMU publisher thread bus=/dev/i2c-1 address=75 frame_id=torso_imu report_interval_us=20000
Oct 02 11:10:10 marengo marengo-pi[643903]: 2026-10-02T16:10:10.515486Z  INFO marengo_pi::imu: IMU session starting
Oct 02 11:10:10 marengo marengo-pi[643903]: marengo-pi commands (stdin):
Oct 02 11:10:10 marengo marengo-pi[643903]:   home
Oct 02 11:10:10 marengo marengo-pi[643903]:   enable [operator_id] [force]
Oct 02 11:10:10 marengo marengo-pi[643903]:   disable
Oct 02 11:10:10 marengo marengo-pi[643903]:   gravity-on | gravity-off
Oct 02 11:10:10 marengo marengo-pi[643903]:   torque-cmd <joint> <nm>
Oct 02 11:10:10 marengo marengo-pi[643903]:   impedance-on | impedance-off
Oct 02 11:10:10 marengo marengo-pi[643903]:   hold-on | hold-at [joint] <rad> | hold-off
Oct 02 11:10:10 marengo marengo-pi[643903]:   wave <joint> <min_rad> <max_rad> <cycles> [half_period_sec]
Oct 02 11:10:10 marengo marengo-pi[643903]:   status
Oct 02 11:10:10 marengo marengo-pi[643903]:   quit
Oct 02 11:10:10 marengo marengo-pi[643903]: 2026-10-02T16:10:10.515538Z  INFO marengo_pi: marengo-pi starting Disabled; calibration history cannot grant current reference (docs/homing.md) hz=200 chappe_hz=25 motor_count=5 interfaces={"can0"} config=/opt/marengo/config

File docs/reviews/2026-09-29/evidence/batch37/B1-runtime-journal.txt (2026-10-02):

Oct 02 11:03:24 marengo systemd[1]: Stopping marengo-pi.service - Marengo Pi runtime (control, CAN, Chappe)...
Oct 02 11:03:24 marengo marengo-pi[635382]: 2026-10-02T16:03:24.658137Z  INFO marengo_pi::imu: IMU session ended cleanly
Oct 02 11:03:24 marengo marengo-pi[635382]: 2026-10-02T16:03:24.658553Z  INFO marengo_pi: shutdown stop delivery evidence; physical stop unconfirmed writes_accepted=true report=Some(StopReport { generation: 3, attempts: [StopAttempt { address: MotorAddress { interface: "can0", device_id: 1 }, action: ZeroSpeed, error: None }, StopAttempt { address: MotorAddress { interface: "can0", device_id: 1 }, action: NeutralMit, error: None }, StopAttempt { address: MotorAddress { interface: "can0", device_id: 1 }, action: Disable, error: None }, StopAttempt { address: MotorAddress { interface: "can0", device_id: 2 }, action: ZeroSpeed, error: None }, StopAttempt { address: MotorAddress { interface: "can0", device_id: 2 }, action: NeutralMit, error: None }, StopAttempt { address: MotorAddress { interface: "can0", device_id: 2 }, action: Disable, error: None }, StopAttempt { address: MotorAddress { interface: "can0", device_id: 3 }, action: ZeroSpeed, error: None }, StopAttempt { address: MotorAddress { interface: "can0", device_id: 3 }, action: NeutralMit, error: None }, StopAttempt { address: MotorAddress { interface: "can0", device_id: 3 }, action: Disable, error: None }, StopAttempt { address: MotorAddress { interface: "can0", device_id: 4 }, action: ZeroSpeed, error: None }, StopAttempt { address: MotorAddress { interface: "can0", device_id: 4 }, action: NeutralMit, error: None }, StopAttempt { address: MotorAddress { interface: "can0", device_id: 4 }, action: Disable, error: None }, StopAttempt { address: MotorAddress { interface: "can0", device_id: 5 }, action: ZeroSpeed, error: None }, StopAttempt { address: MotorAddress { interface: "can0", device_id: 5 }, action: NeutralMit, error: None }, StopAttempt { address: MotorAddress { interface: "can0", device_id: 5 }, action: Disable, error: None }] })
Oct 02 11:03:24 marengo marengo-pi[635382]: 2026-10-02T16:03:24.658606Z  INFO marengo_pi: owner shutdown outcome persist_idle=true status=Complete successful_requests=0 failed_requests=0 publication_failures=0 pending_requests=0 in_flight=false worker_terminated=true worker_error=None coalesced_requests=0 reference_journal=ReferenceJournalDrain { admission_closed: true, queued: 0, in_flight: false, completed_unconsumed: 0, accepted_credits: 0, durable_writes: 0, failed_writes: 0, uncertain_writes: 0, worker_terminated: true, worker_error: None } outcome=ShutdownOutcome { persist_idle: true, stop: Attempted { result: Ok(()), report: Some(StopReport { generation: 3, attempts: [StopAttempt { address: MotorAddress { interface: "can0", device_id: 1 }, action: ZeroSpeed, error: None }, StopAttempt { address: MotorAddress { interface: "can0", device_id: 1 }, action: NeutralMit, error: None }, StopAttempt { address: MotorAddress { interface: "can0", device_id: 1 }, action: Disable, error: None }, StopAttempt { address: MotorAddress { interface: "can0", device_id: 2 }, action: ZeroSpeed, error: None }, StopAttempt { address: MotorAddress { interface: "can0", device_id: 2 }, action: NeutralMit, error: None }, StopAttempt { address: MotorAddress { interface: "can0", device_id: 2 }, action: Disable, error: None }, StopAttempt { address: MotorAddress { interface: "can0", device_id: 3 }, action: ZeroSpeed, error: None }, StopAttempt { address: MotorAddress { interface: "can0", device_id: 3 }, action: NeutralMit, error: None }, StopAttempt { address: MotorAddress { interface: "can0", device_id: 3 }, action: Disable, error: None }, StopAttempt { address: MotorAddress { interface: "can0", device_id: 4 }, action: ZeroSpeed, error: None }, StopAttempt { address: MotorAddress { interface: "can0", device_id: 4 }, action: NeutralMit, error: None }, StopAttempt { address: MotorAddress { interface: "can0", device_id: 4 }, action: Disable, error: None }, StopAttempt { address: MotorAddress { interface: "can0", device_id: 5 }, action: ZeroSpeed, error: None }, StopAttempt { address: MotorAddress { interface: "can0", device_id: 5 }, action: NeutralMit, error: None }, StopAttempt { address: MotorAddress { interface: "can0", device_id: 5 }, action: Disable, error: None }] }) }, mandatory_reference: None, persist: PersistDrainReport { status: Complete, successful_writes: 0, failed_writes: 0, publication_failures: 0, pending_requests: 0, in_flight: false, worker_terminated: true, worker_error: None, coalesced_requests: 0 }, reference_journal: ReferenceJournalDrain { admission_closed: true, queued: 0, in_flight: false, completed_unconsumed: 0, accepted_credits: 0, durable_writes: 0, failed_writes: 0, uncertain_writes: 0, worker_terminated: true, worker_error: None } }
Oct 02 11:03:24 marengo marengo-pi[635382]: 2026-10-02T16:03:24.658701Z  INFO marengo_pi: marengo-pi stopped
Oct 02 11:03:24 marengo systemd[1]: marengo-pi.service: Deactivated successfully.
Oct 02 11:03:24 marengo systemd[1]: Stopped marengo-pi.service - Marengo Pi runtime (control, CAN, Chappe).
Oct 02 11:03:24 marengo systemd[1]: marengo-pi.service: Consumed 18.337s CPU time.
Oct 02 11:03:24 marengo systemd[1]: Started marengo-pi.service - Marengo Pi runtime (control, CAN, Chappe).
Oct 02 11:03:24 marengo marengo-pi[638549]: 2026-10-02T16:03:24.766886Z  INFO marengo_pi: Chappe IPC fanout enabled path=/run/marengo/chappe.sock
Oct 02 11:03:24 marengo marengo-pi[638549]: 2026-10-02T16:03:24.767137Z  INFO marengo_pi::imu: starting IMU publisher thread bus=/dev/i2c-1 address=75 frame_id=torso_imu report_interval_us=20000
Oct 02 11:03:24 marengo marengo-pi[638549]: marengo-pi commands (stdin):
Oct 02 11:03:24 marengo marengo-pi[638549]:   home
Oct 02 11:03:24 marengo marengo-pi[638549]:   enable [operator_id] [force]
Oct 02 11:03:24 marengo marengo-pi[638549]:   disable
Oct 02 11:03:24 marengo marengo-pi[638549]:   gravity-on | gravity-off
Oct 02 11:03:24 marengo marengo-pi[638549]:   torque-cmd <joint> <nm>
Oct 02 11:03:24 marengo marengo-pi[638549]:   impedance-on | impedance-off
Oct 02 11:03:24 marengo marengo-pi[638549]:   hold-on | hold-at [joint] <rad> | hold-off
Oct 02 11:03:24 marengo marengo-pi[638549]:   wave <joint> <min_rad> <max_rad> <cycles> [half_period_sec]
Oct 02 11:03:24 marengo marengo-pi[638549]:   status
Oct 02 11:03:24 marengo marengo-pi[638549]:   quit
Oct 02 11:03:24 marengo marengo-pi[638549]: 2026-10-02T16:03:24.767343Z  INFO marengo_pi: marengo-pi starting Disabled; calibration history cannot grant current reference (docs/homing.md) hz=200 chappe_hz=25 motor_count=5 interfaces={"can0"} config=/opt/marengo/config
Oct 02 11:03:24 marengo marengo-pi[638549]: 2026-10-02T16:03:24.767378Z  INFO marengo_pi::imu: IMU session starting

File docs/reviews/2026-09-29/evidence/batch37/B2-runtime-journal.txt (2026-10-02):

Oct 02 11:17:43 marengo systemd[1]: Stopping marengo-pi.service - Marengo Pi runtime (control, CAN, Chappe)...
Oct 02 11:17:43 marengo marengo-pi[648939]: 2026-10-02T16:17:43.360150Z  INFO marengo_pi: shutdown stop delivery evidence; physical stop unconfirmed writes_accepted=true report=Some(StopReport { generation: 1, attempts: [StopAttempt { address: MotorAddress { interface: "can0", device_id: 1 }, action: ZeroSpeed, error: None }, StopAttempt { address: MotorAddress { interface: "can0", device_id: 1 }, action: NeutralMit, error: None }, StopAttempt { address: MotorAddress { interface: "can0", device_id: 1 }, action: Disable, error: None }, StopAttempt { address: MotorAddress { interface: "can0", device_id: 2 }, action: ZeroSpeed, error: None }, StopAttempt { address: MotorAddress { interface: "can0", device_id: 2 }, action: NeutralMit, error: None }, StopAttempt { address: MotorAddress { interface: "can0", device_id: 2 }, action: Disable, error: None }, StopAttempt { address: MotorAddress { interface: "can0", device_id: 3 }, action: ZeroSpeed, error: None }, StopAttempt { address: MotorAddress { interface: "can0", device_id: 3 }, action: NeutralMit, error: None }, StopAttempt { address: MotorAddress { interface: "can0", device_id: 3 }, action: Disable, error: None }, StopAttempt { address: MotorAddress { interface: "can0", device_id: 4 }, action: ZeroSpeed, error: None }, StopAttempt { address: MotorAddress { interface: "can0", device_id: 4 }, action: NeutralMit, error: None }, StopAttempt { address: MotorAddress { interface: "can0", device_id: 4 }, action: Disable, error: None }, StopAttempt { address: MotorAddress { interface: "can0", device_id: 5 }, action: ZeroSpeed, error: None }, StopAttempt { address: MotorAddress { interface: "can0", device_id: 5 }, action: NeutralMit, error: None }, StopAttempt { address: MotorAddress { interface: "can0", device_id: 5 }, action: Disable, error: None }] })
Oct 02 11:17:43 marengo marengo-pi[648939]: 2026-10-02T16:17:43.360200Z  INFO marengo_pi: owner shutdown outcome persist_idle=true status=Complete successful_requests=0 failed_requests=0 publication_failures=0 pending_requests=0 in_flight=false worker_terminated=true worker_error=None coalesced_requests=0 reference_journal=ReferenceJournalDrain { admission_closed: true, queued: 0, in_flight: false, completed_unconsumed: 0, accepted_credits: 0, durable_writes: 0, failed_writes: 0, uncertain_writes: 0, worker_terminated: true, worker_error: None } outcome=ShutdownOutcome { persist_idle: true, stop: Attempted { result: Ok(()), report: Some(StopReport { generation: 1, attempts: [StopAttempt { address: MotorAddress { interface: "can0", device_id: 1 }, action: ZeroSpeed, error: None }, StopAttempt { address: MotorAddress { interface: "can0", device_id: 1 }, action: NeutralMit, error: None }, StopAttempt { address: MotorAddress { interface: "can0", device_id: 1 }, action: Disable, error: None }, StopAttempt { address: MotorAddress { interface: "can0", device_id: 2 }, action: ZeroSpeed, error: None }, StopAttempt { address: MotorAddress { interface: "can0", device_id: 2 }, action: NeutralMit, error: None }, StopAttempt { address: MotorAddress { interface: "can0", device_id: 2 }, action: Disable, error: None }, StopAttempt { address: MotorAddress { interface: "can0", device_id: 3 }, action: ZeroSpeed, error: None }, StopAttempt { address: MotorAddress { interface: "can0", device_id: 3 }, action: NeutralMit, error: None }, StopAttempt { address: MotorAddress { interface: "can0", device_id: 3 }, action: Disable, error: None }, StopAttempt { address: MotorAddress { interface: "can0", device_id: 4 }, action: ZeroSpeed, error: None }, StopAttempt { address: MotorAddress { interface: "can0", device_id: 4 }, action: NeutralMit, error: None }, StopAttempt { address: MotorAddress { interface: "can0", device_id: 4 }, action: Disable, error: None }, StopAttempt { address: MotorAddress { interface: "can0", device_id: 5 }, action: ZeroSpeed, error: None }, StopAttempt { address: MotorAddress { interface: "can0", device_id: 5 }, action: NeutralMit, error: None }, StopAttempt { address: MotorAddress { interface: "can0", device_id: 5 }, action: Disable, error: None }] }) }, mandatory_reference: None, persist: PersistDrainReport { status: Complete, successful_writes: 0, failed_writes: 0, publication_failures: 0, pending_requests: 0, in_flight: false, worker_terminated: true, worker_error: None, coalesced_requests: 0 }, reference_journal: ReferenceJournalDrain { admission_closed: true, queued: 0, in_flight: false, completed_unconsumed: 0, accepted_credits: 0, durable_writes: 0, failed_writes: 0, uncertain_writes: 0, worker_terminated: true, worker_error: None } }
Oct 02 11:17:43 marengo marengo-pi[648939]: 2026-10-02T16:17:43.360286Z  INFO marengo_pi: marengo-pi stopped
Oct 02 11:17:43 marengo systemd[1]: marengo-pi.service: Deactivated successfully.
Oct 02 11:17:43 marengo systemd[1]: Stopped marengo-pi.service - Marengo Pi runtime (control, CAN, Chappe).
Oct 02 11:17:43 marengo systemd[1]: marengo-pi.service: Consumed 3.694s CPU time.
Oct 02 11:17:43 marengo systemd[1]: Started marengo-pi.service - Marengo Pi runtime (control, CAN, Chappe).
Oct 02 11:17:43 marengo marengo-pi[649684]: 2026-10-02T16:17:43.443519Z  INFO marengo_pi: Chappe IPC fanout enabled path=/run/marengo/chappe.sock
Oct 02 11:17:43 marengo marengo-pi[649684]: 2026-10-02T16:17:43.444407Z  INFO marengo_pi::imu: starting IMU publisher thread bus=/dev/i2c-1 address=75 frame_id=torso_imu report_interval_us=20000
Oct 02 11:17:43 marengo marengo-pi[649684]: 2026-10-02T16:17:43.444621Z  INFO marengo_pi::imu: IMU session starting
Oct 02 11:17:43 marengo marengo-pi[649684]: marengo-pi commands (stdin):
Oct 02 11:17:43 marengo marengo-pi[649684]:   home
Oct 02 11:17:43 marengo marengo-pi[649684]:   enable [operator_id] [force]
Oct 02 11:17:43 marengo marengo-pi[649684]:   disable
Oct 02 11:17:43 marengo marengo-pi[649684]:   gravity-on | gravity-off
Oct 02 11:17:43 marengo marengo-pi[649684]:   torque-cmd <joint> <nm>
Oct 02 11:17:43 marengo marengo-pi[649684]:   impedance-on | impedance-off
Oct 02 11:17:43 marengo marengo-pi[649684]:   hold-on | hold-at [joint] <rad> | hold-off
Oct 02 11:17:43 marengo marengo-pi[649684]:   wave <joint> <min_rad> <max_rad> <cycles> [half_period_sec]
Oct 02 11:17:43 marengo marengo-pi[649684]:   status
Oct 02 11:17:43 marengo marengo-pi[649684]:   quit
Oct 02 11:17:43 marengo marengo-pi[649684]: 2026-10-02T16:17:43.444831Z  INFO marengo_pi: marengo-pi starting Disabled; calibration history cannot grant current reference (docs/homing.md) hz=200 chappe_hz=25 motor_count=5 interfaces={"can0"} config=/opt/marengo/config

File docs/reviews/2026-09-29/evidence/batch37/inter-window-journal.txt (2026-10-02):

Oct 02 10:57:58 marengo systemd[1]: Stopping marengo-pi.service - Marengo Pi runtime (control, CAN, Chappe)...
Oct 02 10:57:58 marengo marengo-pi[593190]: 2026-10-02T15:57:58.805860Z  INFO marengo_pi::imu: IMU session ended cleanly
Oct 02 10:57:58 marengo marengo-pi[593190]: 2026-10-02T15:57:58.808270Z  INFO marengo_pi: shutdown stop delivery evidence; physical stop unconfirmed writes_accepted=true report=Some(StopReport { generation: 89, attempts: [StopAttempt { address: MotorAddress { interface: "can0", device_id: 1 }, action: ZeroSpeed, error: None }, StopAttempt { address: MotorAddress { interface: "can0", device_id: 1 }, action: NeutralMit, error: None }, StopAttempt { address: MotorAddress { interface: "can0", device_id: 1 }, action: Disable, error: None }, StopAttempt { address: MotorAddress { interface: "can0", device_id: 2 }, action: ZeroSpeed, error: None }, StopAttempt { address: MotorAddress { interface: "can0", device_id: 2 }, action: NeutralMit, error: None }, StopAttempt { address: MotorAddress { interface: "can0", device_id: 2 }, action: Disable, error: None }, StopAttempt { address: MotorAddress { interface: "can0", device_id: 3 }, action: ZeroSpeed, error: None }, StopAttempt { address: MotorAddress { interface: "can0", device_id: 3 }, action: NeutralMit, error: None }, StopAttempt { address: MotorAddress { interface: "can0", device_id: 3 }, action: Disable, error: None }, StopAttempt { address: MotorAddress { interface: "can0", device_id: 4 }, action: ZeroSpeed, error: None }, StopAttempt { address: MotorAddress { interface: "can0", device_id: 4 }, action: NeutralMit, error: None }, StopAttempt { address: MotorAddress { interface: "can0", device_id: 4 }, action: Disable, error: None }, StopAttempt { address: MotorAddress { interface: "can0", device_id: 5 }, action: ZeroSpeed, error: None }, StopAttempt { address: MotorAddress { interface: "can0", device_id: 5 }, action: NeutralMit, error: None }, StopAttempt { address: MotorAddress { interface: "can0", device_id: 5 }, action: Disable, error: None }] })
Oct 02 10:57:58 marengo systemd[1]: marengo-pi.service: Deactivated successfully.
Oct 02 10:57:58 marengo marengo-pi[593190]: 2026-10-02T15:57:58.808317Z  INFO marengo_pi: owner shutdown outcome persist_idle=true status=Complete successful_requests=0 failed_requests=0 publication_failures=0 pending_requests=0 in_flight=false worker_terminated=true worker_error=None coalesced_requests=0 reference_journal=ReferenceJournalDrain { admission_closed: true, queued: 0, in_flight: false, completed_unconsumed: 0, accepted_credits: 0, durable_writes: 0, failed_writes: 0, uncertain_writes: 0, worker_terminated: true, worker_error: None } outcome=ShutdownOutcome { persist_idle: true, stop: Attempted { result: Ok(()), report: Some(StopReport { generation: 89, attempts: [StopAttempt { address: MotorAddress { interface: "can0", device_id: 1 }, action: ZeroSpeed, error: None }, StopAttempt { address: MotorAddress { interface: "can0", device_id: 1 }, action: NeutralMit, error: None }, StopAttempt { address: MotorAddress { interface: "can0", device_id: 1 }, action: Disable, error: None }, StopAttempt { address: MotorAddress { interface: "can0", device_id: 2 }, action: ZeroSpeed, error: None }, StopAttempt { address: MotorAddress { interface: "can0", device_id: 2 }, action: NeutralMit, error: None }, StopAttempt { address: MotorAddress { interface: "can0", device_id: 2 }, action: Disable, error: None }, StopAttempt { address: MotorAddress { interface: "can0", device_id: 3 }, action: ZeroSpeed, error: None }, StopAttempt { address: MotorAddress { interface: "can0", device_id: 3 }, action: NeutralMit, error: None }, StopAttempt { address: MotorAddress { interface: "can0", device_id: 3 }, action: Disable, error: None }, StopAttempt { address: MotorAddress { interface: "can0", device_id: 4 }, action: ZeroSpeed, error: None }, StopAttempt { address: MotorAddress { interface: "can0", device_id: 4 }, action: NeutralMit, error: None }, StopAttempt { address: MotorAddress { interface: "can0", device_id: 4 }, action: Disable, error: None }, StopAttempt { address: MotorAddress { interface: "can0", device_id: 5 }, action: ZeroSpeed, error: None }, StopAttempt { address: MotorAddress { interface: "can0", device_id: 5 }, action: NeutralMit, error: None }, StopAttempt { address: MotorAddress { interface: "can0", device_id: 5 }, action: Disable, error: None }] }) }, mandatory_reference: None, persist: PersistDrainReport { status: Complete, successful_writes: 0, failed_writes: 0, publication_failures: 0, pending_requests: 0, in_flight: false, worker_terminated: true, worker_error: None, coalesced_requests: 0 }, reference_journal: ReferenceJournalDrain { admission_closed: true, queued: 0, in_flight: false, completed_unconsumed: 0, accepted_credits: 0, durable_writes: 0, failed_writes: 0, uncertain_writes: 0, worker_terminated: true, worker_error: None } }
Oct 02 10:57:58 marengo marengo-pi[593190]: 2026-10-02T15:57:58.808396Z  INFO marengo_pi: marengo-pi stopped
Oct 02 10:57:58 marengo systemd[1]: Stopped marengo-pi.service - Marengo Pi runtime (control, CAN, Chappe).
Oct 02 10:57:58 marengo systemd[1]: marengo-pi.service: Consumed 2min 14.376s CPU time.
Oct 02 10:58:02 marengo systemd[1]: Started marengo-pi.service - Marengo Pi runtime (control, CAN, Chappe).
Oct 02 10:58:02 marengo marengo-pi[635382]: 2026-10-02T15:58:02.547662Z  INFO marengo_pi: Chappe IPC fanout enabled path=/run/marengo/chappe.sock
Oct 02 10:58:02 marengo marengo-pi[635382]: 2026-10-02T15:58:02.548437Z  INFO marengo_pi::imu: starting IMU publisher thread bus=/dev/i2c-1 address=75 frame_id=torso_imu report_interval_us=20000
Oct 02 10:58:02 marengo marengo-pi[635382]: 2026-10-02T15:58:02.548607Z  INFO marengo_pi::imu: IMU session starting
Oct 02 10:58:02 marengo marengo-pi[635382]: marengo-pi commands (stdin):
Oct 02 10:58:02 marengo marengo-pi[635382]:   home
Oct 02 10:58:02 marengo marengo-pi[635382]:   enable [operator_id] [force]
Oct 02 10:58:02 marengo marengo-pi[635382]:   disable
Oct 02 10:58:02 marengo marengo-pi[635382]:   gravity-on | gravity-off
Oct 02 10:58:02 marengo marengo-pi[635382]:   torque-cmd <joint> <nm>
Oct 02 10:58:02 marengo marengo-pi[635382]:   impedance-on | impedance-off
Oct 02 10:58:02 marengo marengo-pi[635382]:   hold-on | hold-at [joint] <rad> | hold-off
Oct 02 10:58:02 marengo marengo-pi[635382]:   wave <joint> <min_rad> <max_rad> <cycles> [half_period_sec]
Oct 02 10:58:02 marengo marengo-pi[635382]:   status
Oct 02 10:58:02 marengo marengo-pi[635382]:   quit
Oct 02 10:58:02 marengo marengo-pi[635382]: 2026-10-02T15:58:02.548721Z  INFO marengo_pi: marengo-pi starting Disabled; calibration history cannot grant current reference (docs/homing.md) hz=200 chappe_hz=25 motor_count=5 interfaces={"can0"} config=/opt/marengo/config
Oct 02 11:02:18 marengo marengo-pi[635382]: 2026-10-02T16:02:18.618858Z ERROR run_control_loop: marengo_pi: control tick failed error=safety: persistent safety fault 1 (Transport) on None: received CAN error frame; physical bus state and error subscriptions unqualified; qualified recovery unavailable

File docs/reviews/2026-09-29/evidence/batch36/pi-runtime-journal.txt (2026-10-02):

Oct 02 09:26:27 marengo systemd[1]: Stopping marengo-pi.service - Marengo Pi runtime (control, CAN, Chappe)...
Oct 02 09:26:27 marengo marengo-pi[560332]: 2026-10-02T14:26:27.702837Z  INFO marengo_pi: shutdown stop delivery evidence; physical stop unconfirmed writes_accepted=true report=Some(StopReport { generation: 3, attempts: [StopAttempt { address: MotorAddress { interface: "can0", device_id: 1 }, action: ZeroSpeed, error: None }, StopAttempt { address: MotorAddress { interface: "can0", device_id: 1 }, action: NeutralMit, error: None }, StopAttempt { address: MotorAddress { interface: "can0", device_id: 1 }, action: Disable, error: None }, StopAttempt { address: MotorAddress { interface: "can0", device_id: 2 }, action: ZeroSpeed, error: None }, StopAttempt { address: MotorAddress { interface: "can0", device_id: 2 }, action: NeutralMit, error: None }, StopAttempt { address: MotorAddress { interface: "can0", device_id: 2 }, action: Disable, error: None }, StopAttempt { address: MotorAddress { interface: "can0", device_id: 3 }, action: ZeroSpeed, error: None }, StopAttempt { address: MotorAddress { interface: "can0", device_id: 3 }, action: NeutralMit, error: None }, StopAttempt { address: MotorAddress { interface: "can0", device_id: 3 }, action: Disable, error: None }, StopAttempt { address: MotorAddress { interface: "can0", device_id: 4 }, action: ZeroSpeed, error: None }, StopAttempt { address: MotorAddress { interface: "can0", device_id: 4 }, action: NeutralMit, error: None }, StopAttempt { address: MotorAddress { interface: "can0", device_id: 4 }, action: Disable, error: None }, StopAttempt { address: MotorAddress { interface: "can0", device_id: 5 }, action: ZeroSpeed, error: None }, StopAttempt { address: MotorAddress { interface: "can0", device_id: 5 }, action: NeutralMit, error: None }, StopAttempt { address: MotorAddress { interface: "can0", device_id: 5 }, action: Disable, error: None }] })
Oct 02 09:26:27 marengo marengo-pi[560332]: 2026-10-02T14:26:27.702891Z  INFO marengo_pi: owner shutdown outcome persist_idle=true status=Complete successful_requests=0 failed_requests=0 publication_failures=0 pending_requests=0 in_flight=false worker_terminated=true worker_error=None coalesced_requests=0 reference_journal=ReferenceJournalDrain { admission_closed: true, queued: 0, in_flight: false, completed_unconsumed: 0, accepted_credits: 0, durable_writes: 0, failed_writes: 0, uncertain_writes: 0, worker_terminated: true, worker_error: None } outcome=ShutdownOutcome { persist_idle: true, stop: Attempted { result: Ok(()), report: Some(StopReport { generation: 3, attempts: [StopAttempt { address: MotorAddress { interface: "can0", device_id: 1 }, action: ZeroSpeed, error: None }, StopAttempt { address: MotorAddress { interface: "can0", device_id: 1 }, action: NeutralMit, error: None }, StopAttempt { address: MotorAddress { interface: "can0", device_id: 1 }, action: Disable, error: None }, StopAttempt { address: MotorAddress { interface: "can0", device_id: 2 }, action: ZeroSpeed, error: None }, StopAttempt { address: MotorAddress { interface: "can0", device_id: 2 }, action: NeutralMit, error: None }, StopAttempt { address: MotorAddress { interface: "can0", device_id: 2 }, action: Disable, error: None }, StopAttempt { address: MotorAddress { interface: "can0", device_id: 3 }, action: ZeroSpeed, error: None }, StopAttempt { address: MotorAddress { interface: "can0", device_id: 3 }, action: NeutralMit, error: None }, StopAttempt { address: MotorAddress { interface: "can0", device_id: 3 }, action: Disable, error: None }, StopAttempt { address: MotorAddress { interface: "can0", device_id: 4 }, action: ZeroSpeed, error: None }, StopAttempt { address: MotorAddress { interface: "can0", device_id: 4 }, action: NeutralMit, error: None }, StopAttempt { address: MotorAddress { interface: "can0", device_id: 4 }, action: Disable, error: None }, StopAttempt { address: MotorAddress { interface: "can0", device_id: 5 }, action: ZeroSpeed, error: None }, StopAttempt { address: MotorAddress { interface: "can0", device_id: 5 }, action: NeutralMit, error: None }, StopAttempt { address: MotorAddress { interface: "can0", device_id: 5 }, action: Disable, error: None }] }) }, mandatory_reference: None, persist: PersistDrainReport { status: Complete, successful_writes: 0, failed_writes: 0, publication_failures: 0, pending_requests: 0, in_flight: false, worker_terminated: true, worker_error: None, coalesced_requests: 0 }, reference_journal: ReferenceJournalDrain { admission_closed: true, queued: 0, in_flight: false, completed_unconsumed: 0, accepted_credits: 0, durable_writes: 0, failed_writes: 0, uncertain_writes: 0, worker_terminated: true, worker_error: None } }
Oct 02 09:26:27 marengo marengo-pi[560332]: 2026-10-02T14:26:27.702990Z  INFO marengo_pi: marengo-pi stopped
Oct 02 09:26:27 marengo systemd[1]: marengo-pi.service: Deactivated successfully.
Oct 02 09:26:27 marengo systemd[1]: Stopped marengo-pi.service - Marengo Pi runtime (control, CAN, Chappe).
Oct 02 09:26:27 marengo systemd[1]: marengo-pi.service: Consumed 38.069s CPU time.
Oct 02 09:26:27 marengo systemd[1]: Started marengo-pi.service - Marengo Pi runtime (control, CAN, Chappe).
Oct 02 09:26:27 marengo marengo-pi[568641]: 2026-10-02T14:26:27.810904Z  INFO marengo_pi: Chappe IPC fanout enabled path=/run/marengo/chappe.sock
Oct 02 09:26:27 marengo marengo-pi[568641]: 2026-10-02T14:26:27.811297Z  INFO marengo_pi::imu: starting IMU publisher thread bus=/dev/i2c-1 address=75 frame_id=torso_imu report_interval_us=20000
Oct 02 09:26:27 marengo marengo-pi[568641]: 2026-10-02T14:26:27.811534Z  INFO marengo_pi::imu: IMU session starting
Oct 02 09:26:27 marengo marengo-pi[568641]: marengo-pi commands (stdin):
Oct 02 09:26:27 marengo marengo-pi[568641]:   home
Oct 02 09:26:27 marengo marengo-pi[568641]:   enable [operator_id] [force]
Oct 02 09:26:27 marengo marengo-pi[568641]:   disable
Oct 02 09:26:27 marengo marengo-pi[568641]:   gravity-on | gravity-off
Oct 02 09:26:27 marengo marengo-pi[568641]:   torque-cmd <joint> <nm>
Oct 02 09:26:27 marengo marengo-pi[568641]:   impedance-on | impedance-off
Oct 02 09:26:27 marengo marengo-pi[568641]:   hold-on | hold-at [joint] <rad> | hold-off
Oct 02 09:26:27 marengo marengo-pi[568641]:   wave <joint> <min_rad> <max_rad> <cycles> [half_period_sec]
Oct 02 09:26:27 marengo marengo-pi[568641]:   status
Oct 02 09:26:27 marengo marengo-pi[568641]:   quit
Oct 02 09:26:27 marengo marengo-pi[568641]: 2026-10-02T14:26:27.811669Z  INFO marengo_pi: marengo-pi starting Disabled; calibration history cannot grant current reference (docs/homing.md) hz=200 chappe_hz=25 motor_count=5 interfaces={"can0"} config=/opt/marengo/config
Oct 02 09:26:49 marengo marengo-pi[568641]: 2026-10-02T14:26:49.841067Z ERROR run_control_loop: marengo_pi: control tick failed error=safety: persistent safety fault 1 (Transport) on None: received CAN error frame; physical bus state and error subscriptions unqualified; qualified recovery unavailable

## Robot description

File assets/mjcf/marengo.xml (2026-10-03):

<mujoco model="marengo">
  <!-- Mirrors assets/urdf/marengo.urdf (right 5-DOF bench). -->
  <!-- Body <inertial> blocks are the URDF CAD values (docs/commissioning/right-arm-urdf-from-cad-2026-10-03.md),
       so sim gravity matches the dynamics model. MuJoCo fullinertia order is Ixx Iyy Izz Ixy Ixz Iyz. -->
  <compiler angle="radian"/>
  <option gravity="0 0 -9.81"/>
  <worldbody>
    <body name="base_link">
      <inertial pos="0 0 0" mass="0.001" fullinertia="1e-6 1e-6 1e-6 0 0 0"/>
      <geom type="cylinder" size="0.04 0.05" rgba="0.5 0.5 0.5 1"/>
      <body name="right_shoulder_pitch_link" pos="0 0 0">
        <inertial pos="-0.00378 0.06933 -0.00005" mass="1.0101" fullinertia="0.001536 0.0009527 0.001158 1.603e-05 -2.844e-08 2.068e-07"/>
        <joint name="right_shoulder_pitch" type="hinge" axis="0 1 0" range="-0.9 3.25"/>
        <geom type="sphere" size="0.03" rgba="0.6 0.6 0.6 1"/>
        <body name="right_shoulder_roll_link" pos="0.05 0 0">
          <inertial pos="-0.00209 -0.00001 -0.07141" mass="0.4925" fullinertia="0.0004919 0.0005279 0.0004215 4.083e-07 0.0001046 2.811e-08"/>
          <joint name="right_shoulder_roll" type="hinge" axis="1 0 0" range="-0.05 3.14159"/>
          <geom type="sphere" size="0.03" rgba="0.65 0.65 0.65 1"/>
          <body name="right_upper_arm_link" pos="0.08 0 0">
            <inertial pos="0.00003 -0.00779 -0.21516" mass="0.5075" fullinertia="0.000923 0.001014 0.0003144 -6.824e-09 -4.374e-07 -5.757e-05"/>
            <joint name="right_upper_arm_yaw" type="hinge" axis="0 0 1" range="-1.57 1.57"/>
            <geom type="capsule" fromto="0 0 0 0 0 -0.24" size="0.03" rgba="0.23 0.51 0.96 1"/>
            <body name="right_forearm_link" pos="0 0 -0.24">
              <inertial pos="0.00066 0.00342 -0.06048" mass="0.3910" fullinertia="0.000469 0.0004819 0.0001943 1.038e-06 -9.693e-06 -7.524e-05"/>
              <joint name="right_elbow_pitch" type="hinge" axis="0 1 0" range="-0.50 1.2"/>
              <geom type="capsule" fromto="0 0 0 0 0 -0.2" size="0.025" rgba="0.35 0.6 0.95 1"/>
              <body name="right_hand_link" pos="0 0 -0.20">
                <inertial pos="-0.00003 0 -0.04123" mass="0.0822" fullinertia="0.0001839 0.0001838 6.152e-05 -5.002e-10 -1.688e-07 1.74e-09"/>
                <joint name="right_lower_arm_yaw" type="hinge" axis="0 1 0" range="-1.6 1.6"/>
                <geom type="capsule" fromto="0 0 0 0 0 -0.06" size="0.02" rgba="0.45 0.7 0.98 1"/>
              </body>
            </body>
          </body>
        </body>
      </body>
    </body>
  </worldbody>
</mujoco>

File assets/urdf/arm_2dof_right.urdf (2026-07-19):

<?xml version="1.0"?>
<!-- Right 2-DOF bench: shoulder pitch (torso) → shoulder roll (arm sub-asm).
     Matches config/bringup/arm_2dof_right/robot.yaml.
     Axes per hardware/docs/kinematics.md (right arm table). -->
<robot name="marengo_arm_2dof_right">
  <link name="base_link">
    <inertial>
      <mass value="0.001"/>
      <inertia ixx="1e-6" ixy="0" ixz="0" iyy="1e-6" iyz="0" izz="1e-6"/>
    </inertial>
    <visual>
      <origin xyz="0 0 0" rpy="0 0 0"/>
      <geometry>
        <cylinder radius="0.04" length="0.10"/>
      </geometry>
      <material name="mount_gray">
        <color rgba="0.5 0.5 0.5 1"/>
      </material>
    </visual>
  </link>
  <link name="right_shoulder_pitch_link">
    <inertial>
      <origin xyz="0 0 0" rpy="0 0 0"/>
      <mass value="0.3"/>
      <inertia ixx="0.002" ixy="0" ixz="0" iyy="0.002" iyz="0" izz="0.002"/>
    </inertial>
  </link>
  <link name="right_shoulder_roll_link">
    <inertial>
      <origin xyz="0.05 0 0" rpy="0 0 0"/>
      <mass value="0.3"/>
      <inertia ixx="0.002" ixy="0" ixz="0" iyy="0.002" iyz="0" izz="0.002"/>
    </inertial>
  </link>
  <link name="right_upper_arm_stub">
    <inertial>
      <mass value="0.7"/>
      <origin xyz="0 0 -0.36" rpy="0 0 0"/>
      <inertia ixx="0.001" ixy="0" ixz="0" iyy="0.001" iyz="0" izz="0.0001"/>
    </inertial>
    <visual>
      <origin xyz="0 0 -0.2" rpy="0 0 0"/>
      <geometry>
        <cylinder radius="0.03" length="0.4"/>
      </geometry>
      <material name="arm_blue">
        <color rgba="0.23 0.51 0.96 1"/>
      </material>
    </visual>
  </link>
  <joint name="right_shoulder_pitch" type="revolute">
    <parent link="base_link"/>
    <child link="right_shoulder_pitch_link"/>
    <origin xyz="0 0 0" rpy="0 0 0"/>
    <axis xyz="0 1 0"/>
    <limit lower="-0.9" upper="3.25" effort="60" velocity="2.0"/>
    <safety_controller soft_lower_limit="-0.872665" soft_upper_limit="3.20" k_position="10" k_velocity="1"/>
  </joint>
  <joint name="right_shoulder_roll" type="revolute">
    <parent link="right_shoulder_pitch_link"/>
    <child link="right_shoulder_roll_link"/>
    <origin xyz="0.05 0 0" rpy="0 0 0"/>
    <axis xyz="1 0 0"/>
    <limit lower="-0.05" upper="3.14159" effort="60" velocity="2.0"/>
    <safety_controller soft_lower_limit="-0.05" soft_upper_limit="3.14159" k_position="10" k_velocity="1"/>
  </joint>
  <joint name="right_upper_arm_fixed" type="fixed">
    <parent link="right_shoulder_roll_link"/>
    <child link="right_upper_arm_stub"/>
    <origin xyz="0.08 0 0" rpy="0 0 0"/>
  </joint>
</robot>

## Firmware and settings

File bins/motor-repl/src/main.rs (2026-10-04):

//! One-shot motor CLI for bench inspection, independent stop, and physical zeroing.
//!
//! `disable` and the exit stop are deliberately independent of Davout: see
//! [`stop`].

mod stop;

use std::collections::BTreeSet;
use std::env;
use std::path::PathBuf;

use armee_dynamics::{gravity_model_from_urdf, DynamicsModel};
use berthier::ControlLoop;
use marengo_config::{
    load_control_config, load_motor_stop_targets, load_motors_config, load_robot_config,
    resolve_config_dir, resolve_reference_journal_path, resolve_repo_root, resolve_urdf_path,
};
use robstride::RuntimeBus;
use tracing::info;

fn repo_root() -> PathBuf {
    resolve_repo_root()
}

fn usage() {
    eprintln!(
        "motor-repl — one-shot bench motor CLI (Davout → robstride)\n\
         Usage:\n  \
         motor-repl [--config-dir PATH] [--can-interface can0] status\n  \
           motor-repl disable\n  \
           motor-repl set-zero <joint> [--sign-tested]\n  \
           motor-repl protocol-inspect [joint...]  (all joints when none listed)\n  \
           motor-repl gravity-preview [q...]  (robot.yaml joint order)\n\
         Reference grants are process-local; reference and enable in one long-running marengo-pi process.\n\
         set-zero runs the qualified physical reference workflow (ADR 0036); its current grant\n\
         ends with this process.\n\
         disable reads only drive addresses from motors.yaml and sends one Disable to each.\n\
         protocol-inspect (ADR 0037) stops every drive, then reads firmware version, MCU id and\n\
         registers (incl. 0x7028 CAN timeout) one query at a time; it never enables or writes.\n\
         set-zero arms an independent exit stop on SIGTERM/SIGINT/SIGHUP and error exit.\n\
         Uses SocketCAN; prefer test harness or simulation before live CAN.\n\
         Env: MARENGO_ROOT, MARENGO_CONFIG_DIR (e.g. config/bringup/shoulder_pitch_dual)"
    );
}

#[derive(Debug, PartialEq, Eq)]
struct BusArgs {
    can_interface: Option<String>,
    config_dir: Option<PathBuf>,
    command_args: Vec<String>,
}

fn parse_bus_args(args: &[String]) -> Result<BusArgs, String> {
    let Some(program) = args.first() else {
        return Err("missing program name".into());
    };
    let mut parsed = BusArgs {
        can_interface: env::var("MARENGO_CAN_INTERFACE").ok(),
        config_dir: env::var("MARENGO_CONFIG_DIR").ok().map(PathBuf::from),
        command_args: vec![program.clone()],
    };
    let mut i = 1;
    while i < args.len() {
        match args[i].as_str() {
            "--can-interface" => {
                let value = args
                    .get(i + 1)
                    .filter(|value| !value.starts_with("--"))
                    .ok_or("--can-interface requires an interface name")?;
                parsed.can_interface = Some(value.clone());
                i += 2;
            }
            "--config-dir" => {
                let value = args
                    .get(i + 1)
                    .filter(|value| !value.starts_with("--"))
                    .ok_or("--config-dir requires a path")?;
                parsed.config_dir = Some(PathBuf::from(value));
                i += 2;
            }
            value if value.starts_with("--") => {
                return Err(format!("global option {value} must precede the subcommand"));
            }
            _ => {
                if let Some(option) = args[i..]
                    .iter()
                    .find(|arg| matches!(arg.as_str(), "--can-interface" | "--config-dir"))
                {
                    return Err(format!(
                        "global option {option} must precede the subcommand"
                    ));
                }
                parsed.command_args.extend_from_slice(&args[i..]);
                break;
            }
        }
    }
    Ok(parsed)
}

fn parse_gravity_pose(args: &[String], joint_count: usize) -> Result<Vec<f64>, String> {
    let values = args.get(2..).ok_or("missing gravity-preview command")?;
    if values.is_empty() {
        return Ok(vec![0.0; joint_count]);
    }
    if values.len() != joint_count {
        return Err(format!(
            "expected either zero or {joint_count} joint angles, got {}",
            values.len()
        ));
    }
    values
        .iter()
        .map(|value| {
            value
                .parse::<f64>()
                .map_err(|_| format!("invalid joint angle: {value}"))
        })
        .collect()
}

/// `disable`: the independent stop. It reads only the drive addresses from
/// `motors.yaml` and sends each drive a Disable, then a type-24 Off, so a
/// missing `control.yaml`, URDF, corrupt calibration history or a down CAN
/// interface cannot prevent it from reaching the drives it can reach, and no
/// drive is left streaming for the next owner. Exit 0 only when every drive's
/// Disable and Off were accepted by its interface.
fn run_disable(root: &std::path::Path, interface: Option<&str>) -> i32 {
    let targets = match load_motor_stop_targets(root) {
        Ok(targets) => targets,
        Err(error) => {
            eprintln!("disable: cannot read drive addresses from motors.yaml: {error}");
            eprintln!("disable: NO stop frame was sent; use the physical E-stop");
            return 1;
        }
    };
    let addresses = stop::stop_addresses(&targets, interface);
    if addresses.is_empty() {
        eprintln!("disable: motors.yaml lists no drives; NO stop frame was sent");
        return 1;
    }
    let report = stop::disable_drives_socketcan(&addresses);
    print!("{report}");
    report_disable_outcome(&report)
}

/// Summarize the `disable` command's report; 0 only when every frame was sent.
fn report_disable_outcome(report: &stop::StopReport) -> i32 {
    if report.all_sent() {
        println!(
            "disabled: Disable and type-24 Off sent to all {} drives (queued on the bus, not drive-confirmed)",
            report.drives.len()
        );
        return 0;
    }
    report_stop_failures(report, "disable");
    1
}

/// Name the drives a stop did not reach, and the ones it may leave streaming.
fn report_stop_failures(report: &stop::StopReport, context: &str) {
    if report.failed() > 0 {
        eprintln!(
            "{context} INCOMPLETE: {} of {} drives were not reached; use the physical E-stop",
            report.failed(),
            report.drives.len()
        );
    }
    if report.reporting_off_failed() > 0 {
        eprintln!(
            "{context}: type-24 Off not sent to {} of {} drives; they may keep streaming and \
             the next marengo-pi start can latch Transport",
            report.reporting_off_failed(),
            report.drives.len()
        );
    }
}

/// Everything the exit stop needs, resolved before any drive can be touched.
struct ExitStop {
    addresses: Vec<robstride::MotorAddress>,
}

impl ExitStop {
    /// Resolve the drive addresses and install the signal-driven stop. A
    /// command that can leave a drive enabled refuses to start without both.
    fn arm(root: &std::path::Path, interface: Option<&str>) -> Result<Self, String> {
        let targets = load_motor_stop_targets(root)
            .map_err(|error| format!("cannot read drive addresses from motors.yaml: {error}"))?;
        let addresses = stop::stop_addresses(&targets, interface);
        if addresses.is_empty() {
            return Err("motors.yaml lists no drives".into());
        }
        stop::install_signal_stop(addresses.clone())?;
        eprintln!(
            "motor-repl: exit stop armed for {} drives (SIGTERM/SIGINT/SIGHUP and error exit)",
            addresses.len()
        );
        Ok(Self { addresses })
    }

    fn run(&self) {
        eprintln!("motor-repl: exit stop, disabling every drive");
        let report = stop::disable_drives_socketcan(&self.addresses);
        eprint!("{report}");
        report_stop_failures(&report, "motor-repl: exit stop");
    }
}

fn main() {
    let args: Vec<String> = env::args().collect();
    let parsed = match parse_bus_args(&args) {
        Ok(parsed) if parsed.command_args.len() >= 2 => parsed,
        Ok(_) => {
            marengo_support::init_tracing();
            usage();
            std::process::exit(1);
        }
        Err(error) => {
            marengo_support::init_tracing();
            eprintln!("motor-repl: {error}");
            usage();
            std::process::exit(1);
        }
    };
    if let Some(dir) = parsed.config_dir {
        env::set_var("MARENGO_CONFIG_DIR", dir);
    }
    marengo_support::init_tracing();

    let can_interface = parsed.can_interface;
    let args = parsed.command_args;
    let root = repo_root();
    let command = args[1].clone();
    if !is_supported_command(&command) {
        eprintln!("unsupported command: {command}");
        usage();
        std::process::exit(1);
    }
    if command == "disable" {
        std::process::exit(run_disable(&root, can_interface.as_deref()));
    }

    let exit_stop = if stop::arms_exit_stop(&command) {
        match ExitStop::arm(&root, can_interface.as_deref()) {
            Ok(exit_stop) => Some(exit_stop),
            Err(error) => {
                eprintln!("{command}: refused, cannot arm the exit stop: {error}");
                std::process::exit(1);
            }
        }
    } else {
        None
    };

    let code = run_command(&root, can_interface, &args);
    if let Some(exit_stop) = &exit_stop {
        if stop::exit_stop_required(&command, code) {
            exit_stop.run();
        }
    }
    std::process::exit(code);
}

fn run_status(root: &std::path::Path, interface: Option<&str>) -> i32 {
    let control = match load_control_config(root) {
        Ok(config) => config,
        Err(error) => {
            eprintln!("control.yaml: {error}");
            return 1;
        }
    };
    let motors = match load_motors_config(root) {
        Ok(config) => config,
        Err(error) => {
            eprintln!("motors.yaml: {error}");
            return 1;
        }
    };
    let bus = match interface {
        Some(interface) => RuntimeBus::socketcan(interface),
        None => RuntimeBus::socketcan_from_motors(&motors),
    };
    match bus {
        Ok(_bus) => {}
        Err(error) => {
            eprintln!("open SocketCAN: {error}");
            return 1;
        }
    }
    println!(
        "configuration: {} joints, loop_hz={}, SocketCAN opened (no Supervisor constructed)",
        motors.motors.len(),
        control.control.loop_hz
    );
    0
}

fn run_gravity_preview(root: &std::path::Path, args: &[String]) -> i32 {
    let robot = match load_robot_config(root) {
        Ok(config) => config,
        Err(error) => {
            eprintln!("robot.yaml: {error}");
            return 1;
        }
    };
    let urdf = match resolve_urdf_path(root, &robot) {
        Ok(path) => path,
        Err(error) => {
            eprintln!("URDF: {error}");
            return 1;
        }
    };
    let model = match gravity_model_from_urdf(&urdf, &robot.robot.joints) {
        Ok(model) => model,
        Err(error) => {
            eprintln!("gravity model: {error}");
            return 1;
        }
    };
    let q = match parse_gravity_pose(args, robot.robot.joints.len()) {
        Ok(q) => q,
        Err(error) => {
            eprintln!("{error}");
            return 1;
        }
    };
    let tau = match model.gravity_torques(&q) {
        Ok(tau) => tau,
        Err(error) => {
            eprintln!("tau_g: {error}");
            return 1;
        }
    };
    for (name, torque) in robot.robot.joints.iter().zip(tau.iter()) {
        println!("{name}: tau_g = {torque:.4} Nm");
    }
    0
}

/// Dispatches read-only commands without constructing a Supervisor; all other
/// supported commands load configuration, open CAN and construct their owner.
fn is_read_only_command(command: &str) -> bool {
    matches!(command, "status" | "gravity-preview")
}
fn is_supported_command(command: &str) -> bool {
    matches!(
        command,
        "status" | "disable" | "set-zero" | "protocol-inspect" | "gravity-preview"
    )
}

/// `CanTimeout` (0x7028) counts: 20000 = 1 s, 0 = off.
const CAN_TIMEOUT_COUNTS_PER_SECOND: f64 = 20_000.0;

fn parameter_label(parameter: robstride::ParameterId) -> &'static str {
    use robstride::ParameterId;
    match parameter {
        ParameterId::RunMode => "run_mode",
        ParameterId::MechPos => "mech_pos",
        ParameterId::MechVel => "mech_vel",
        ParameterId::CanTimeout => "can_timeout",
        ParameterId::ZeroSta => "zero_sta",
        ParameterId::AddOffset => "add_offset",
        _ => "register",
    }
}

/// One line per drive; `pi_protocol_inspect` reads `firmware=` and `can_timeout=`.
fn format_inspection(drive: &davout::DriveProtocolInspection) -> String {
    use robstride::{ParameterId, ParameterValue};
    let mut line = format!(
        "inspect {} {}:{} firmware={} uid={}",
        drive.joint, drive.address.interface, drive.address.device_id, drive.firmware, drive.uid
    );
    for (parameter, value) in &drive.parameters {
        let label = parameter_label(*parameter);
        match (parameter, value) {
            (ParameterId::CanTimeout, ParameterValue::U32(0)) => {
                line.push_str(&format!(" {label}=0 (off)"));
            }
            (ParameterId::CanTimeout, ParameterValue::U32(counts)) => line.push_str(&format!(
                " {label}={counts} ({:.3} s)",
                f64::from(*counts) / CAN_TIMEOUT_COUNTS_PER_SECOND
            )),
            (_, ParameterValue::U8(v)) => line.push_str(&format!(" {label}={v}")),
            (_, ParameterValue::U16(v)) => line.push_str(&format!(" {label}={v}")),
            (_, ParameterValue::U32(v)) => line.push_str(&format!(" {label}={v}")),
            (_, ParameterValue::F32(v)) => line.push_str(&format!(" {label}={v:.4}")),
        }
    }
    line
}

/// `protocol-inspect [joint...]` (ADR 0037). The owner transmits nothing at
/// construction; Davout stops every drive before and after the read queries.
fn run_protocol_inspect(
    root: &std::path::Path,
    bus: RuntimeBus,
    joints: &[String],
    bus_label: &str,
) -> i32 {
    let mut owner = match davout::Supervisor::from_repo_for_protocol_inspection(root, bus) {
        Ok(owner) => owner,
        Err(e) => {
            eprintln!("protocol-inspect: {e}");
            return 1;
        }
    };
    match owner.inspect_drive_protocol(joints) {
        Ok(drives) => {
            for drive in &drives {
                println!("{}", format_inspection(drive));
            }
            println!(
                "protocol-inspect: {} drives read, all drives Disabled again (SocketCAN {bus_label})",
                drives.len()
            );
            0
        }
        Err(e) => {
            eprintln!("protocol-inspect refused: {e}");
            1
        }
    }
}

fn run_command(root: &std::path::Path, can_interface: Option<String>, args: &[String]) -> i32 {
    let command = args.get(1).map(String::as_str).unwrap_or_default();
    if !is_supported_command(command) {
        eprintln!("unsupported command: {command}");
        return 1;
    }
    if is_read_only_command(command) {
        return match command {
            "status" => run_status(root, can_interface.as_deref()),
            "gravity-preview" => run_gravity_preview(root, args),
            _ => {
                eprintln!("unsupported command: {command}");
                return 1;
            }
        };
    }
    let control = match load_control_config(root) {
        Ok(c) => c,
        Err(e) => {
            eprintln!("control.yaml: {e}");
            return 1;
        }
    };
    let motors = match load_motors_config(root) {
        Ok(c) => c,
        Err(e) => {
            eprintln!("motors.yaml: {e}");
            return 1;
        }
    };
    let bus = match can_interface.as_deref() {
        Some(interface) => match RuntimeBus::socketcan(interface) {
            Ok(bus) => bus,
            Err(e) => {
                eprintln!("open SocketCAN {interface}: {e}");
                return 1;
            }
        },
        None => match RuntimeBus::socketcan_from_motors(&motors) {
            Ok(bus) => bus,
            Err(e) => {
                eprintln!("open SocketCAN from motors.yaml: {e}");
                return 1;
            }
        },
    };
    let bus_label = can_interface
        .clone()
        .unwrap_or_else(|| "motors.yaml".to_string());
    let can_interfaces: BTreeSet<_> = motors
        .motors
        .iter()
        .map(|motor| motor.can_interface.as_str())
        .collect();
    info!(
        bus = %bus_label,
        motor_count = motors.motors.len(),
        interfaces = ?can_interfaces,
        "motor-repl opened SocketCAN"
    );
    if args[1] == "protocol-inspect" {
        return run_protocol_inspect(root, bus, &args[2..], &bus_label);
    }
    // Only set-zero needs the physical reference owner and its journal; every
    // other command keeps the ordinary owner so a journal resource fault can
    // never block it.
    let built = if args[1] == "set-zero" {
        match resolve_reference_journal_path(root, resolve_config_dir(root)) {
            Ok(journal) => ControlLoop::from_repo_with_physical_reference(
                root,
                bus,
                journal,
                control.control.loop_hz,
                control.control.chappe_state_hz,
            ),
            Err(e) => {
                eprintln!("reference journal path: {e}");
                return 1;
            }
        }
    } else {
        ControlLoop::from_repo(
            root,
            bus,
            control.control.loop_hz,
            control.control.chappe_state_hz,
        )
    };
    let mut loop_ctrl = match built {
        Ok(l) => l,
        Err(e) => {
            eprintln!("control loop: {e}");
            return 1;
        }
    };

    match args[1].as_str() {
        "set-zero" => {
            let Some(joint) = args.get(2).map(String::as_str) else {
                eprintln!("missing joint name");
                return 1;
            };
            let sign_tested = args.iter().any(|a| a == "--sign-tested");
            // Davout owns preflight, the qualified physical acquisition and the
            // journal commit; the drives are stopped before this returns, and
            // `main` runs the exit stop if it returns an error.
            match loop_ctrl
                .supervisor_mut()
                .calibrate_joint_zero(joint, "bench", sign_tested)
            {
                Ok(pos) => {
                    println!("set-zero {joint} verified pos={pos:.4} rad (SocketCAN {bus_label})");
                }
                Err(e) => {
                    eprintln!("set-zero refused: {e}");
                    return 1;
                }
            }
        }
        _ => {
            usage();
            return 1;
        }
    }
    0
}
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

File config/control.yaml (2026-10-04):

# Control tuning for right 5-DOF bench (roll + pitch + yaw + elbow + lower-arm yaw).
control:
  loop_hz: 200
  chappe_state_hz: 25
  comm_watchdog_ms: 100
  tau_ff_rate_limit_nm_per_s: 60.0
  disable_on_exit: true
  bench:
    # Free-drive Set Limits: keep encoder feedback while limp (Disabled/Ready).
    active_reporting_diagnostics: true

  # Single-drive loss while Active (ADR 0038). A joint with
  # `on_drive_loss: shed_subtree` is admitted at marengo-pi startup only if the
  # offline gravity bound passes on every joint that keeps holding:
  # max |τ_g| + max |Δτ_g| (frozen shed angles) + tau_margin_nm <= its tau_ff cap.
  drive_loss:
    hold_window_s: 5.0
    lower_velocity_rad_s: 0.25
    lower_settle_s: 3.0
    lower_max_s: 10.0
    tau_margin_nm: 0.5

  motor_type_defaults:
    rs00:
      kp_max: 500
      kd_max: 5
      tau_ff_max_nm: 3.0
      velocity_max_rad_s: 2.0
    rs02:
      kp_max: 500
      kd_max: 5
      tau_ff_max_nm: 3.0
      velocity_max_rad_s: 2.0
    rs03:
      kp_max: 5000
      kd_max: 100
      tau_ff_max_nm: 5.0
      velocity_max_rad_s: 2.0

  actuator_groups:
    shoulder_pitch:
      joints: [right_shoulder_pitch]
      velocity_max_rad_s: 2.5
    shoulder_roll:
      joints: [right_shoulder_roll]
      velocity_max_rad_s: 2.5
    upper_arm_yaw:
      joints: [right_upper_arm_yaw]
      velocity_max_rad_s: 2.0
    elbow:
      joints: [right_elbow_pitch]
      velocity_max_rad_s: 1.5
    lower_arm_yaw:
      joints: [right_lower_arm_yaw]
      velocity_max_rad_s: 1.5

  joints:
    right_shoulder_roll:
      motor_type: rs03
      gravity_comp:
        kp: 0.0
        kd: 0.0
        ki: 0.0
      impedance:
        kp: 18.0
        kd: 3.0
        ki: 5.0
      # Slew too slow through the friction knee stick-slips (R1 hitch at q≈0.023).
      # Keep small holds on traj with a moderate cruise — between snap (1.25/4.5) and struggle.
      # a=2.5 made decel ~12% of a 0.785 move (felt hesitant in the last 10–20%); a=4.0 ≈8%.
      position_slew_rad_s: 0.35
      position_slew_max_lead_rad: 0.12
      position_trajectory_threshold_rad: 0.12
      position_trajectory_velocity_rad_s: 0.7
      position_trajectory_accel_rad_s2: 4.0
      position_trajectory_velocity_deadband_rad: 0.02
      position_hold_trim_rad: 0.0
      position_limit_margin_min_rad: 0.01
      position_limit_margin_k_v_s: 0.02
      position_limit_margin_k_stop: 0.5
      # ~30 mrad: enable/settle jitter at taught Set Limits hard (not a motors.yaml pad).
      position_limit_measured_fault_slack_rad: 0.03
      # Soft from Set Limits (ADR 0009 inset); hard lower kept at URDF -0.05 for enable margin.
      position_soft_lower_rad: -0.04088089871406555
      position_soft_upper_rad: 3.088609407424926
      friction:
        fc: 0.08
        fv: 0.0
        fo: 0.0
        k: 10.0
    right_shoulder_pitch:
      motor_type: rs03
      gravity_comp:
        kp: 0.0
        kd: 0.0
        ki: 0.0
      impedance:
        # 40 (was 18): closes the friction + ripple dead zone (fs + ripple)/kp from ≈ 58 to
        # ≈ 26 mrad without the assist's hidden near-rest stiffness (ADR 0040).
        kp: 40.0
        # scaled_pd: drive kd (kd_mit), constant on the wire in Position. 5 (was 3): the
        # 2026-10-04 motion suite fits friction falling from ≈ 0.6 Nm at 0.05 rad/s to 0.37
        # above 0.2 rad/s, a slope down to −(fs − fc)/v_b ≈ −3.5 Nm·s/rad that kd 3 did not
        # out-damp (stick-slip on slow waves and slow moves). ADR 0039 Phase 3 bench fix.
        # 6 (was 5) with kp 40 (ADR 0040): fitted-plant gate worst 50 ms speed overshoot 16.8 %
        # vs 20.5 % at kd 5 on the J 0.111 variant; predicted peak total torque 3.71 of 5 Nm.
        kd: 6.0
        ki: 5.0
      # ADR 0039 Phase 3 bench trial (pitch only; every other joint stays legacy).
      # e1 = position_slew_max_lead_rad (stop band) and e0 = e1/4 (full-rate band), the
      # ADR defaults. Tuned in law_gates `pitch_bench_trial_meets_bench_criteria` against
      # the 2026-10-04 fitted plant (kp unchanged):
      # - integral band 0.02 ≈ the static dead zone fs/kp (0.37/18); the 0.1 default
      #   carries a wound-up integral into the next slew (up to 21 % speed overshoot);
      # - reference accel 1.5 (was 4.5): fc·k·a·dt bounds the τ_ff step per tick
      #   (0.079 Nm at 4.5 with fc 0.353), and without J·a feed-forward the stop
      #   overshoot is ≈ I·a/kp (up to 27 mrad at 4.5). Docs: ADR 0039 Phase 3 trial.
      # - friction fs 0.65 / v_b 0.08 (Stribeck, fitted to the motion-suite traces) and k 15
      #   (was 10): the reference friction rises to the low-speed level the joint sees; the
      #   law's J·a + friction slew limit keeps the τ_ff step ≤ 0.05 Nm.
      position_law: scaled_pd
      position_time_scale_e0_rad: 0.03
      position_integral_band_rad: 0.02
      position_integral_leak_s: 2.0
      # ADR 0040 slow-speed law (docs/reviews/2026-10-04-control-audit-pitch-slow-speed.md):
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

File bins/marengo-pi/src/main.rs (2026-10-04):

//! Marengo Pi runtime: CAN I/O, control loop, Chappe telemetry, operator commands.

mod degraded;
mod enable_gate;
#[cfg(test)]
mod enable_gate_tests;
mod gravity_preflight;
#[cfg(test)]
mod gravity_preflight_tests;
#[cfg(target_os = "linux")]
mod host_metrics;
#[cfg(all(target_os = "linux", feature = "linux-i2c"))]
mod imu;
#[cfg(test)]
mod ipc_wiring_tests;
mod limit_persist;
mod motion_owner;
#[cfg(test)]
mod motion_owner_chappe_tests;
mod overlay;
#[cfg(test)]
mod reference_busy_overlay_tests;
#[cfg(test)]
mod reference_dispatch_tests;
#[cfg(test)]
mod reference_journal_shutdown_tests;
mod reference_queue;
#[cfg(test)]
mod reference_shutdown_tests;
#[cfg(test)]
mod safety_publication_tests;
#[cfg(test)]
mod safety_receive_diagnostic_tests;
#[cfg(test)]
mod shutdown_tests;
#[cfg(test)]
mod stop_path_tests;
/// Berthier's feedback/fixture helpers, loaded once for every test module.
#[cfg(test)]
#[path = "../../../crates/berthier/tests/support/mod.rs"]
mod test_support;

use std::collections::BTreeSet;
use std::env;
use std::io::{self, BufRead};
use std::path::{Path, PathBuf};
use std::sync::atomic::{AtomicBool, Ordering};
use std::sync::mpsc::{self, Receiver, Sender};
use std::sync::Arc;
use std::thread;
use std::time::{Duration, Instant, SystemTime, UNIX_EPOCH};

use armee_proto::prost::Message;
use armee_proto::{
    ActiveReportingLeaseAction, ActiveReportingLeaseRequest, ControlMode as ProtoControlMode,
    EnableRequest, Fault, FaultSeverity, Heartbeat, MitCommandBatch, MitJointCommand,
    MotorStatusPollRequest, OperationalMode as ProtoOpMode, SafetyState, SetZeroRequest,
};
use berthier::{
    proto_control_mode, ControlLoop, ControlMode, GainOverride, LoopError, TickPhaseAverages,
};
use chappe::topics::{
    TOPIC_ACTIVE_REPORTING_LEASE, TOPIC_ENABLE, TOPIC_HEARTBEAT, TOPIC_MOTOR_STATUS_POLL,
    TOPIC_SAFETY, TOPIC_SET_ZERO, TOPIC_TESTING_MIT_BATCH,
};
use chappe::Bus;
use davout::{
    DavoutError, ExitReportingReport, MotorBus, OperationalMode, ReferenceHandle,
    ReferenceTerminal, StopReport, DEFAULT_LEASE_TTL,
};
use enable_gate::{emit, EnableGate, PreflightFor, PreflightRefusal};
use gravity_preflight::{GravitySweep, SliceBudget, SweepAbort, SweepStats, SweepStep};
use marengo_config::{
    load_control_config, load_motors_config, resolve_config_dir, resolve_repo_root,
    resolve_urdf_path,
};
use robstride::RuntimeBus;
use tracing::{debug, error, info, warn};

use crate::limit_persist::{PersistDrainReport, PersistDrainStatus};
use crate::motion_owner::{
    classify_stdin, publish_audit, report_refusal, resolve_owner, CommandClass, CommandSource,
    MotionLease, MOTION_OWNER_ENV,
};
use crate::reference_queue::{ReferenceEvent, ReferenceQueue};

/// Stdin reference queue: Davout handles in flight, stdin commands deferred.
type PiReferenceQueue = ReferenceQueue<ReferenceHandle, PiCommand>;

/// Audit operator for stdin `home <joint>... sign-tested`.
const STDIN_REFERENCE_OPERATOR: &str = "bench";

fn repo_root() -> PathBuf {
    resolve_repo_root()
}

fn timestamp_ms() -> u64 {
    SystemTime::now()
        .duration_since(UNIX_EPOCH)
        .map(|d| d.as_millis() as u64)
        .unwrap_or(0)
}

fn proto_operational_mode(mode: OperationalMode) -> i32 {
    match mode {
        OperationalMode::Disabled => ProtoOpMode::Disabled as i32,
        OperationalMode::Ready => ProtoOpMode::Ready as i32,
        OperationalMode::Active => ProtoOpMode::Active as i32,
    }
}

enum PiCommand {
    /// Plain `home`: readiness check only (no reference acquisition).
    Home,
    /// `home <joint>... sign-tested`: queue physical reference per joint.
    HomeJoints {
        joints: Vec<String>,
        sign_tested: bool,
    },
    /// `force`/`--force` tokens are accepted and ignored: nothing bypasses the
    /// gravity saturation preflight (docs/safety.md).
    Enable {
        operator_id: String,
    },
    Disable,
    GravityOn,
    GravityOff,
    TorqueCmd {
        joint: String,
        tau_nm: f64,
    },
    ImpedanceOn,
    ImpedanceOff,
    HoldOn,
    HoldAt {
        joint: Option<String>,
        position_rad: f64,
    },
    Wave {
        joint: String,
        min_rad: f64,
        max_rad: f64,
        cycles: u32,
        half_period_sec: f64,
    },
    HoldOff,
    /// Degraded hold only (ADR 0038): lower the holding joints to rest now.
    Lower,
    Status,
    Quit,
}

fn parse_number<T>(token: &str, command: &str, field: &str) -> Result<T, String>
where
    T: std::str::FromStr,
{
    token.parse().map_err(|_| {
        let error = format!("{command}: invalid {field} value {token:?}");
        eprintln!("{error}");
        error
    })
}
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

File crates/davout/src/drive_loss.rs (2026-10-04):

//! Single-drive loss while Active: subtree shed, degraded hold, hard deadline
//! (ADR 0038).
//!
//! A qualifying loss disables the lost joint and every joint distal to it with
//! one type-4 Disable per address, inside the call that judged the lapse, and
//! keeps the proximal joints Active. The controller then holds and lowers them;
//! Davout owns the episode's deadline and ends every episode with an
//! all-address stop and a latched `Communication` fault (restart required).
//! A shed address is never commanded again in this process except Disable.

use std::time::{Duration, Instant};

use marengo_config::OnDriveLoss;
use robstride::{DriveMode, MotorAddress};
use tracing::warn;

use crate::{
    motor_for_joint, ControlMode, DavoutError, DeviceFaultEvidence, FaultClass, MitBatchScratch,
    MotorBus, OperationalMode, Supervisor,
};

/// Replies to host writes made before a shed may still be read this long after
/// it: one control period of writes plus the longest measured MIT reply
/// latency (4.65 ms), doubled. A non-Reset frame from a shed address read later
/// latches `DriveState` and stops every drive.
pub const SHED_REPLY_GRACE: Duration = Duration::from_millis(20);

/// A joint whose drive loss may shed its subtree, installed by the controller
/// once the offline gravity bound admitted it (`on_drive_loss: shed_subtree`).
#[derive(Debug, Clone, PartialEq, Eq)]
pub struct DriveLossPlan {
    pub joint: String,
    /// `joint` and every configured joint distal to it.
    pub shed: Vec<String>,
}

/// A degraded episode in progress: the shed subtree is disabled, the holding
/// joints stay Active until the controller lowers them or the deadline passes.
#[derive(Debug, Clone, PartialEq)]
pub struct DegradedEpisode {
    pub lost_joint: String,
    /// The lost joint and every joint distal to it, all disabled.
    pub shed_joints: Vec<String>,
    /// Active joints that keep holding, in configured motor order.
    pub holding_joints: Vec<String>,
    /// Last admitted position of each shed joint (joint space, rad): the gravity
    /// model's frozen angles.
    pub frozen_positions: Vec<(String, f64)>,
    pub since: Instant,
    /// Davout stops every drive at this instant whatever the controller does.
    pub deadline: Instant,
}

/// How a degraded episode ended. Every end stops every drive and latches.
#[derive(Debug, Clone, Copy, PartialEq, Eq)]
pub enum DegradedEnd {
    /// The controller reported the holding joints at rest.
    LowerComplete,
    /// Davout's deadline passed first.
    Deadline,
    /// Any other all-address stop: operator disable, E-stop, a fault, a second loss.
    Stopped,
}

impl DegradedEnd {
    pub fn as_str(self) -> &'static str {
        match self {
            Self::LowerComplete => "lower complete",
            Self::Deadline => "deadline",
            Self::Stopped => "stop",
        }
    }
}

/// The retained end of the process's degraded episode.
#[derive(Debug, Clone, PartialEq)]
pub struct DegradedOutcome {
    pub lost_joint: String,
    pub end: DegradedEnd,
    pub at: Instant,
}
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

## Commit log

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2026-07-19 feat(pi): actuator overlay via GainOverride (gains-only) (#65)
    * feat(pi): actuator overlay via GainOverride (gains-only)
    Land Pi tuning overlay on current main without touching Berthier tick
    or planner/gravity laws. Runtime MIT maps to the existing Testing-page
    GainOverride path (kp/kd/ki/fc, clamped); pos/vel/torque_ff rejected.
    Config overlay uses clone-then-commit + atomic YAML write with over-max
    gain rejection before persist.
    * fix(review): gate RuntimeMit under GravityComp and harden overlay
    Reject GainOverride tuning in GravityComp/TorqueOnly, refuse negative
    gains, audit broadcast lag, and keep live config aligned if reload
    fails after persist.
    * fix(pi): defer ConfigOverlay per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
    [lib.rs, main.rs]
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2026-07-19 fix(bench): allow slight negative elbow lower limit at zero
    Encoder noise near mechanical zero was ~-0.4 mrad, which tripped Davout
    keepalive hard limits when URDF/motors lower was exactly 0 and dropped
    Enable back to Disabled.
    [arm_4dof_right.urdf, motors.yaml]
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2026-07-20 fix(set-zero): harden calibration path and Set Limits gates
    Always disable after partial enable failure, require sign attestation,
    share Motion rate limits across client_ids, drain set-zero before enable,
    and raise the listen proposal span/sample floor before Apply.
    [http.rs, lib.rs, main.rs]
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2026-07-20 fix(davout): keep type-24 feedback for Set Limits free-drive
    Arm active reporting whenever motors are not ACTIVE so Consul can
    sample joint motion while limp (Disabled/Ready); enable the bench flag.
    [control.yaml, lib.rs]
2026-07-20 fix(robstride): decode type-24 active-reporting as MIT feedback
    Motors report free-drive positions on comm type 24; ingest those frames
    the same way as OperationStatus so Set Limits can see motion while limp.
    [bus.rs]
2026-07-20 feat(consul): enriched subsystem modal with enhanced-logging lease
    Replace the inventory drawer with a centered detail modal and add a
    per-joint Active Reporting lease path (gateway Diagnostics bucket →
    Davout) so opening an actuator requests type-24 feedback without Armed/Dummy wording.
    [http.rs, lib.rs, main.rs]
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2026-07-20 fix(gateway): allow unauthenticated GET /config/snapshot
    Deployed Consul cannot bake MARENGO_GATEWAY_LOG_TOKEN into static assets,
    so read-only config snapshot was 401ing on every page load. Keep the token
    gate on config patch and log routes.
    [config.rs]
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2026-07-20 fix(config): expect active_reporting_diagnostics enabled
    control.yaml flipped the flag for Set Limits free-drive; update the
    parse smoke test to match the committed config.
    [lib.rs]
2026-07-20 style: apply rustfmt to unformatted workspace files
    CI cargo fmt --check failed on gateway/pi/davout/kinematics
    formatting drift already present on main.
    [http.rs, lib.rs, main.rs]
2026-07-20 fix(davout): isolate enable TX from Ready type-24 frames
    With active_reporting_diagnostics on, Ready and Active sync emit
    type-24 frames. Disable diagnostics and clear the TX log before
    request_enable so the lifecycle smoke test asserts enable +
    write_parameter only.
    [lib.rs]
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2026-07-22 feat(consul): Auto Learn for compound tests via local Cursor BFF
    Add stage-capped crawl→walk→run teach drafts through tools/compound-auto-learn,
    rename Record Movement to Manual Movement, and resolve gateway control_limits
    velocity from actuator_groups so Auto Learn fail-closed checks see real caps.
    [config.rs]
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2026-07-22 fix(limits): use Davout live hard as Consul Range SoT
    Inventory/Testing/enable feedback now prefer ActuatorLimitSnapshot
    (URDF ∩ bench) over disk soft/bench, publish soft on the snapshot, pad
    Set Limits hard by 30 mrad, and keep CAN txqueuelen at 1000 so enable
    does not trip ENOBUFS.
    [motors.yaml]
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2026-07-22 fix(berthier): finish hold approach without P-creep
    Restart a short trapezoid from measured q when Hold latches short of
    target, and soften roll traj so R1 tracks without mid-knee hitch.
    [control.yaml]
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2026-07-22 fix(berthier): home residual finish from above only
    Lead-follow treated target=0 as short only past home, so return stuck
    above ~0.018 then oscillated upward from pull-through undershoot.
    Also raise roll traj accel 2.5→4.0 to shorten outbound decel hesitation.
    [control.yaml]
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2026-07-22 style: rustfmt files blocking CI check
    Pre-existing fmt drift on main-side limit/profile modules.
    [lib.rs]
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2026-07-22 fix(config): speed elevated pitch descent for wave return
    Raise the elevated_shoulder_pitch_fall clamp from 0.05 to 0.45 rad/s so
    4-DOF wave pose can lower at a human pace instead of ~30s crawls.
    [control.yaml]
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2026-07-22 refactor(berthier): extract MitFeedforward for non-Position modes
    Pack GravityComp/Impedance/TorqueOnly behind one compose module with
    YAML gains, clear sticky overrides on G-comp enter, and fail-closed
    validation that gravity_comp kp/kd/ki stay zero.
    [lib.rs]
2026-07-22 fix(berthier): gate gain overrides and reject NaN gravity_comp
    Prevent Testing/overlay from stashing stiffness under G-comp/Disabled
    and close the fail-closed validation hole for non-finite gravity_comp.
    [lib.rs]
2026-07-23 refactor(berthier): extract GainRuntime for override and ramp resolve
    Centralize Testing overrides and mode-transition ramp in GainRuntime with a single resolve_all path; MitFeedforward consumes pre-resolved wire gains.
    [lib.rs]
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2026-07-24 refactor(davout): expose JointFeedback and close MotorAddress leak
    Stop re-applying direction/gear on joint reads and keep Berthier/Pi above the bus-address seam.
    [lib.rs, main.rs]
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2026-07-24 test(davout): cover refresh→joint_feedback with inverted scale
    Lock the real RX path so a raw motor-space cache regression fails the suite.
    [lib.rs]
2026-07-24 feat(marengo-candump): add deep module with inspect seam
    Introduce Candump::inspect_path/inspect_bytes with validated CanId,
    explicit TimestampMode, and contract fixtures covering delta, absolute,
    malformed, gzip, sort, and regression.
    [lib.rs]
2026-07-24 refactor(marengo-store): delegate candump to deep module
    Replace private parsers with Candump::inspect_path, drop
    candump_frame_index via migration 3, and project new Frame/Summary
    fields at the gateway JSON boundary.
    [lib.rs]
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2026-07-24 feat(gateway): candump DTO refresh, latest summary, enrich inject
    Map marengo-candump Summary/Frame to JSON with joint/comm_type, add
    GET /logs/sessions/latest/candump/summary, and soft-fail enrichment
    to plain when motors.yaml is unavailable.
    [http.rs, main.rs]
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2026-08-09 fix(candump): accept default ASCII can-utils lines (#87)
    Harness logs use `candump -t z` without `-L`; parse `[dlc] XX…` as well as
    `ID#HEX`. Add a Pi-shaped fixture and document HTTP alias vs shape-change
    honesty in ADR 0001.
    [lib.rs]
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2026-08-11 fix(config): shoulder pitch CAN id 1, roll id 2 (#125)
    * fix(config): map right shoulder pitch to CAN id 1
    Hardware reprogrammed pitch→1 / roll→2. Update motors.yaml SoT (and
    paired recv_can_id), assert both IDs in marengo-config, and add a
    rerunnable verify script.
    * docs: mirror pitch=1 / roll=2 across inventory and bench guides
    Update Consul fixtures, AGENTS, hardware ADR 0001, commissioning docs,
    and MCP probe strings to match the new motors.yaml mapping.
    * chore(check): gate shoulder CAN id mapping in CI
    Run verify-shoulder-can-ids.py from chec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
    [motors.yaml]
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2026-08-11 fix(deploy): Set Limits Apply stays durable SoT across deploys (#122)
    Preserve taught limits across install-pi, keep Telemetry read-only for Apply, and re-assert Active Reporting on silence/heartbeat so free-drive sensing stays live.
    [lib.rs]
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2026-08-11 fix(consul): poll motor status instead of page-wide AR
    Hardware Online facets now use a ~2s Disable (type-4) solicit via
    gateway → Davout instead of Active Reporting leases on every on-CAN
    joint. Sheet/modal type-24 leases stay for Set Limits sensing.
    [http.rs, lib.rs, main.rs]
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2026-08-11 fix(sensing): gate status poll on AR, TTL Online, rate-limit headroom
    Address PR #131 interrogate findings: skip Disable solicit when type-24
    already desired, best-effort TX, free-drive feedback TTL for Offline,
    revert unused multi-lease hook, 2.5s poll with burst-2 + 429 backoff.
    [http.rs, lib.rs, main.rs]
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2026-08-11 fix(consul): persist taught Set Limits hard without ±30 mrad pad
    Apply was silently widening motors.yaml hard by DEFAULT_HARD_MARGIN_RAD,
    so saving -1.40–3.19 refreshed as -1.43–3.22. Store taught hard; cover
    enable/settle jitter via Davout measured-fault slack (30 mrad).
    [control.yaml, lib.rs]
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2026-08-11 fix(berthier): enforce gravity-off τ_cmd≡0 and extract latch
    Address thermo-nuclear Medium+ findings on PR #166: enter_torque_only_zero
    clears latch on gravity-off, set_torque_cmd enters TorqueOnly and rejects
    non-finite values, TorqueCmdLatch moves out of loop.rs, and a wire tick
    test proves τ_cmd packing through ControlLoop.
    [lib.rs, main.rs]
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2026-08-11 fix(config): flip right_elbow_pitch direction to match URDF
    Live sign check showed motor +q lowered the forearm; set direction -1 so
    joint +q is up/forward (playbook Wave / URDF +Y).
    [motors.yaml]
2026-08-11 fix(config): flip right_lower_arm_yaw direction (+ outwards)
    Operator sign check: joint +q twisted inwards with direction +1; set
    direction -1 so +q is outwards / -q inwards.
    [motors.yaml]
2026-08-12 fix(config): flip right_upper_arm_yaw direction (+ outwards)
    Match lower_arm_yaw operator convention after Ch3 sign jog showed
    +q twisted inwards with direction +1.
    [motors.yaml]
2026-08-12 fix(config): align robot.yaml joint order to URDF pitch→roll (#178)
    * fix(config): align robot.yaml joint order to URDF pitch→roll
    CAN ids were already pitch=1 / roll=2 (#125). robot.yaml still listed
    roll before pitch, so dynamics q vectors and gravity-preview labels
    disagreed with the URDF chain and motors.yaml. Reorder to pitch-first,
    permute playbook pose vectors, and print τ_g by robot.yaml joint name.
    * chore(mcp): pitch-first MARENGO_JOINT_SUBSET order
    Match robot.yaml / URDF chain in harness profile subsets and tests.
    Co-authored-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
    [robot.yaml]
2026-08-12 feat(commissioning): adopt demo-derived wave_pose for right_arm (#179)
    * feat(commissioning): adopt demo-derived wave_pose for right_arm
    Replace paper wave_pose [2.75, 0.42, 0, 0.55, 0] with operator-demo
    main cluster [1.80, 0.68, -0.11, 0.97, 1.47] from #170 captures.
    Retarget Consul Wave raise keyframes (include lower_arm_yaw) and clip
    nativeWave elbow span to taught upper (~1.03).
    * fix(config): sync marengo-config tests with pitch→roll and sign flips
    Update joint-subset order expectation to robot.yaml / URDF pitch→roll
    and motors.yaml direction fixtures for yaw/elbow/lower after #177/#178.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
    [lib.rs]
2026-08-12 fix(control): scale RS02/RS00 cruise from roll comfort ratio (#180)
    Apply roll RS03 comfort cruise (0.70) / manual no-load @48 V (20.94)
    ≈ 3.34% to RS02/RS00 trajectory cruise: yaw/elbow 1.43, lower 1.10.
    Keep pitch 1.25 and roll 0.70 unchanged.
    [control.yaml]
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2026-10-02 Require a runtime session and bounded work for the local limits mirror (#244)
    * fix(tooling): add runtime local mirror authentication and bounded execution
    * fix(tooling): bind real limits mirror to its checkout and qualify HTTP bounds
    * docs(tooling): qualify local mirror repairs and retain generation acceptance
    * docs(tooling): bind native Pi workspace qualification to mirror source
    [main.rs]
2026-10-02 fix(gateway): enforce access and enter credentials at runtime (#245)
    * test(gateway): freeze isolated access refusal proof and policy contract
    * fix(gateway): share fail-closed HTTP access before handler work
    * fix(gateway): admit bounded streams and use runtime browser credentials
    * build(consul): refresh generated subscription schema checksum
    * refactor(consul): share telemetry frame retirement and cleanup
    * docs: qualify gateway access on native Pi and CI
    * docs: bind portable gateway receipts to canonical log bytes
    [config.rs, http.rs]
2026-10-02 Add bounded durable virtual reference history (#246)
    * docs: record gateway delivery and prepare reference history journal
    * feat(davout): add bounded durable virtual reference history
    * fix(davout): bind distinct history resources before lazy journal open
    * fix(davout): reserve the SQLite sidecar namespace
    * fix(davout): compare existing reference file identities
    * fix(davout): guard resource types before identity opens
    * docs: qualify durable virtual reference history
    * docs: record final reference history reviews
    [lib.rs, main.rs, simulation.rs]
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2026-10-03 perf(davout): remove per-tick clones, rollback copies and SipHash from admission and feedback
    Staged limiter/wrong-sign commit, cached motor addresses revalidated against public config, reused scratch buffers, FxHash private maps, precomputed reference binding side.
    [lib.rs]
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2026-10-03 feat(davout): add physical Robstride reference backend core
    Physical owners (Supervisor::from_repo_with_physical_reference) acquire
    one joint per transaction: baseline stop and reporting off, drain,
    type-0 MCU identity, target-only arm, SetZero, a type-2 ack popped after
    the request, then a requested type-17 mechPos readback within tolerance.
    Cleanup stops before storage; the durable journal records
    physical_robstride evidence; the commit consumer selects per-joint
    grants that accumulate under one policy.
    Grants bind the acquisition UID and a coordinate epoch. Identity change
    or absence at Enable re-verification, coordinate discontinuity,
    Calibration mode, or silence beyond comm_watchdog_ms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
    [lib.rs, simulation.rs, simulation_reference.rs]
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2026-10-03 feat(berthier): build physical reference owners for motor-repl set-zero
    Add marengo_config::resolve_reference_journal_path (MARENGO_REFERENCE_JOURNAL,
    else reference-journal.sqlite3 beside the calibration history) and
    ControlLoop::from_repo_with_physical_reference. motor-repl set-zero now runs
    the qualified physical workflow; other commands keep the ordinary owner so a
    journal resource fault never blocks Disable.
    [lib.rs, main.rs]
2026-10-03 feat(marengo-pi): acquire physical references from stdin home and Chappe set-zero
    marengo-pi builds the physical reference owner. Stdin
    'home <joint>... sign-tested' and robot/set_zero feed one non-blocking queue
    pumped after each tick, printing 'reference <joint> current pos=' or
    'reference <joint> failed: ...'. Other stdin commands are deferred until the
    queue drains; disable, quit and E-stop cancel it and discard deferred
    commands. Plain 'home' remains the readiness check.
    [main.rs]
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2026-10-03 fix(davout): order post-enable drive mode against the Enable echo
    A SocketCAN write only queues a frame. On the bench a roll Reset report
    went on the wire before its queued Enable but was read after Davout went
    Active, so the strict Run check latched a DriveState fault.
    SocketCAN sockets now receive their own transmissions (loopback +
    CAN_RAW_RECV_OWN_MSGS) and declare CanBus::echoes_transmissions. robstride
    surfaces this host's exact Enable frame as an ordered EnableEchoObservation
    and never decodes own echoes as feedback, replies or reports (including a
    type-24 command resolving to the host id).
    Davout keeps each enabled address pending until its Enable echo is popped.
    Frames popped befo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
    [bus.rs, lib.rs]
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2026-10-03 fix(berthier): add hold-tracking fuse and grid-aware home classification
    Position hold now latches targets within two feedback counts of zero as
    home (0.0), so a hold-on one encoder count off zero classifies exactly
    like an exact-zero latch. A symmetric HoldTracking fuse faults when
    |q - target| > 0.03 rad for 2000 ms while net commanded torque
    (tau_p + tau_ff) opposes the target with no measured progress, covering
    a home hold that sags under a wrong gravity model. AscentStall and
    HoldTracking errors report q, target, tau_p, tau_ff and tau_g at trip.
    [lib.rs]
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2026-10-03 test: read live URDF limits and masses instead of literals
    Four tests built their inputs from literal strings and values in
    assets/urdf/marengo.urdf (the elbow's old "-0.50 / 1.2" limits and a
    0.3 kg link), so any taught-limit or mass change broke them:
    - davout limit_patch_expands_urdf_when_past_current_hard and
    marengo-config expand_file_covers_motors_and_round_trips expect the
    expand-only lower bound min(current, -0.5) instead of -0.5.
    - marengo-config completeness_warns_missing_mass_on_zero_mass_link zeroes
    the pitch link's mass whatever its value.
    - marengo-gateway activate tests raise the elbow's current hard upper by
    0.25 rad (raise_elbow_upper) instead of replacing a literal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
    [lib.rs]
2026-10-03 fix(urdf): right-arm joint origins and inertials from CAD
    Replace the placeholder right-arm geometry with values read from
    cad/assemblies/marengo_arm_right_asm through the SolidWorks MCP:
    - Joint origins from the actuator mates: roll axis crosses the pitch axis
    73.5 mm outboard of the pitch output face, upper-arm yaw 1.15 mm off it,
    elbow 230.4 mm below, RS00 output face 99.7 mm below the elbow (was
    0.05/0.08 m forward offsets that put -1.6 Nm on pitch at rest).
    - Link mass/COM/inertia: RobStride datasheet masses with CAD COMs, PLA
    parts estimated from CAD volume and area at 20 % infill; hidden
    actuator copies embedded in three part files are excluded.
    - Hard limits copied from th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
    [marengo.urdf]
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2026-10-03 fix(davout): stagger Enable and type-24 writes to stop mcp251x RX overruns
    Three can0 rx_over_errors since boot each latched marengo-pi's persistent
    Transport fault (CAN_ERR_CRTL_RX_OVERFLOW). The MCP2515 holds two received
    frames and every Robstride command solicits one reply.
    Candump evidence (2026-10-03):
    - 14:24:14.527 overrun: identity, Enable+RunMode x5, type-24 Off x5 and
    neutral MIT put 70 frames on can0 in 12.2 ms (35 host, 35 drive replies;
    2.9 RX/ms, ~81% bus; densest 2 ms: 8 RX + 7 TX). Reads stalled ~0.7 ms
    (-1.95 -> -1.25 ms), then two replies and the next host echo arrived
    40-60 us apart (wire minimum ~130 us), i.e. both buffers full.
    - 14:10:27 startup overrun: five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
    [lib.rs]
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2026-10-03 fix(davout): settle type-24 Off on the wire before every Enable
    Bench 2026-10-03 14:55:24 (rev 6a1bb9d), `home <five right-arm joints>
    sign-tested`: right_lower_arm_yaw failed "invalid feedback for
    right_lower_arm_yaw: unexpected drive mode Reset for Disabled; no qualified
    factory-calibration context" (gateway log_events; no candump that run).
    Cause: drives keep type-24 reporting across host processes (14:51:33
    candump: all five streaming before marengo-pi started). With 6a1bb9d's
    paced sync only m1/m2 Ons were applied before their references, and the
    reference baseline turned Off only applied streams, so m3-m5 kept
    reporting Reset at 100 Hz through ArmTarget (14:51 candump: m5 report
    1.25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
    [bus.rs, lib.rs]
2026-10-03 fix(davout): re-request identity during the post-SetZero blackout
    About 535 ms after a SetZero every Robstride drive transmits nothing
    for 48-57 ms and never answers a type-0 request it received meanwhile
    (candumps 2026-10-03 14:51:33 and 15:34:09, all five drives). The
    15:34 gravity calibration's Enable admission sent pitch's type-0 at
    1.1756 s inside its blackout (1.1264-1.1798 s), so enable failed with
    "device identity reply missing at admission" and revoked the grant.
    Enable admission now asks a still-silent target again every 10 ms and
    waits up to 100 ms from the first request. Only replies popped after
    the first request count; a changed UID or a missing reply still
    revokes without any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
    [lib.rs]
2026-10-03 fix(davout): hold each Enable past its drive's post-SetZero blackout
    Bench candump (rev 15542aa): every Robstride drive goes silent for
    48-57 ms about 535 ms after receiving a SetZero (type 6). An Enable
    written into that window is never acted on, so the drive stays in Reset
    and the session latches a persistent DriveState fault.
    - robstride: own SetZero echoes surface as `EchoedCommand::SetZero`.
    - davout: each address's latest SetZero is recorded at its host echo
    (reference write time until the echo is read). On echoing buses no
    Enable, nor the gate Off before it, goes to that address until
    `POST_SET_ZERO_QUIET` (650 ms) has passed. `enable_targets` keeps such a
    target pending and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
    [bus.rs, lib.rs]
2026-10-03 fix(berthier): never latch a Position target before enable completes
    Berthier reads 0.0 for a joint without session pose, and enable_targets
    returns while Enables can still be held (stagger, or a just-zeroed
    drive's 650 ms post-SetZero quiet). A hold-on sent on `enabled` could
    latch 0.0 as that joint's hold target.
    - berthier: `enable_completion()` requires Active, no unwritten Enable and
    fresh session pose for every Active joint. hold-on, hold-at, wave and
    setpoint retargets drain feedback, re-arm, then refuse with
    `LoopError::EnableIncomplete` ("waiting for enable to complete: ...")
    and latch nothing until it holds. `ENABLE_COMPLETION_TIMEOUT` = 2 s.
    - marengo-pi: `EnableGate` pri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
    [enable_gate.rs, lib.rs, main.rs]
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2026-10-03 fix(robstride): RS03 MIT velocity scale is ±20 rad/s, not ±50
    RS03 manual §4.1.2 (revisions 251112, 260112, 260713) and bench capture
    cd-20261003T145133Z (K = 20.05 rad/s, r = 0.999) agree on ±20. With ±50,
    RS03 feedback velocity decoded 2.5x high, v_des and danger-zone velocity
    clamps reached the drive at 0.4x, and reference continuity accepted 2.5x
    the physical rate.
    Adds a regression test decoding literal bench status frames, updates
    fixtures that hardcoded the old scale, and documents ranges, configs
    tuned under the old scale, and the open RS00 question.
    [motor_type.rs]
2026-10-03 fix(davout): size POST_SET_ZERO_QUIET from measured firmware timing
    Analyse 8 bench captures (394,887 frames, 125 SetZeros, 245 Enables) with
    marengo-log-cli firmware-timing and commit the derived profile and
    behaviour doc. The post-SetZero blackout starts 511-543 ms after SetZero
    (614 ms once, right_elbow_pitch 15:34) and lasts 45-61 ms; latest end
    667 ms. POST_SET_ZERO_QUIET 650 -> 800 ms (end + 100 ms, rounded to 50).
    The firmware emulator gains a timing model (Enable/identity reply delay,
    report period, per-drive blackout start/length) covering every measured
    range; tests/firmware_profile.rs asserts that coverage and the margin of
    POST_SET_ZERO_QUIET and the identity admission window.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
    [lib.rs]
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2026-10-03 fix(berthier): gain runtime errors on non-parallel input and derives ramp from loop_hz
    L-berthier-06: wire_gains_now/resolve_all return GainShapeError instead of assert_eq! panics in the tick path; LoopError::GainShape discards motion intent. L-berthier-12: GainRuntime::for_loop_hz sizes the ramp to ~100 ms (20 ticks at 200 Hz).
    [lib.rs]
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
